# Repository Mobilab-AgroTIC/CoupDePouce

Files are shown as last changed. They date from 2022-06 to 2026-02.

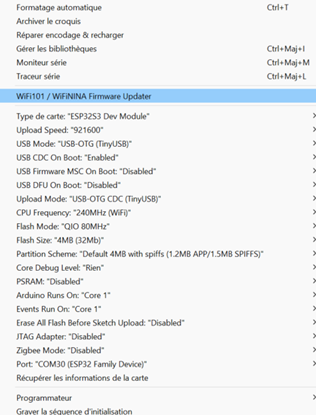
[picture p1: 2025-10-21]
firmware/CoupDePouce_ESP32S3_LTE/config.png

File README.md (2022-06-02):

# CoupDePouce

Le projet permet d'activer un mécansime à distance, via la construction d'un 'doigt connecté', par envoi de SMS. Le système total coûte environ 60€.
Dans ce tutoriel, nous allons d'abord cosntruire le module (1), puis le programmer (2) pour qu'il s'actionne à la récéption d'un SMS.

# 1. Construction du système CoupDePouce

## 1.1. Matériel nécessaire

CoupDePouce nécéssite : 
  - une carte Arduino [MKR GSM 1400](https://www.kubii.fr/26-arduino/2911-arduino-mkr-gsm-1400-3272496301078.html) ou [NB 1500](https://www.gotronic.fr/art-carte-arduino-mkr-nb-1500-abx00019-28733.htm) : 40€
  - Une antenne associée
  - Un forfait téléphonique le moins cher possible : le site [monpetitforfait](https://www.monpetitforfait.com/comparatif-forfaits-mobiles-2-euros) propose les bons plans du moment, il est assez facile de trouver un forfait à 2€/mois chez [Prixtel](https://www.prixtel.com/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) ou [Syma](https://www.symamobile.com/forfait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). Free propose un forfait à 0€/mois si vous êtes déja client chez eux.
  - un moteur "pas à pas" [28byj-48](https://fr.aliexpress.com/item/32906617266.html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) avec sa carte ULN2003 (inclue) : 2€
  - Un [cable micro USB data](https://fr.aliexpress.com/item/32958208619.html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) (Attention : si vous avez déja ce cable pour votre téléphone ou autre, il faut être bien sûr que l'on peut echanger de la donnée via ce câble (data sync), et pas uniquement recharger)
  - Un [adaptateur 220V/USB](https://fr.aliexpress.com/item/1005002021554317.html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) (vous en avez peut-être un qui traine chez vous...?)
  - des [cables Dupont Femelle-Femelle](https://fr.aliexpress.com/item/4000848184096.html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) Bien choisir le cable femelle-femelle de 40cm, comme le montre la photo 1 : 

  

## 1.2. Montage du système 

Le montage éléctronique est très simple. Il faut impérativement brancher l'antenne sur la carte, puis les câbles comme suit :

MOTEUR <-> ARDUINO

- **"-"** <-> **pin GND**
- **"5V"** <-> **pin VCC**
- **IN1** <-> **pin 6**
- **IN2** <-> **pin 7**
- **IN3** <-> **pin 8**
- **IN4** <-> **pin 9**

# 2. Installation et paramétrage du logiciel Arduino

## 2.1. Installation d'Arduino

Si ceci n'est pas encore fait, il faut au préalable installer le [logiciel Arduino](https://www.arduino.cc/en/software) sur son ordinateur. Choisissez l'installation pour votre ordinateur (Windows, linux, mac, etc) comme le montre la photo 2 :


L'installation vous posera quelques questions, dites "oui" à tout.

## 2.2. Paramétrage d'Arduino pour la carte MKR GSM 1400 ou NB 1500

Une fois installé, on lance le logiciel Arduino. Une fenêtre s'ouvre.



On ouvre Outils > Type de cartes > Gestionnaire de Cartes



On recherce depuis la barre de recherche MKR. Une librairie est trouvée : "Arduino SAMD Boards". On clique sur Installer. L'installation peut prendre 1min.



On selectionne finalement la carte utilisée dans outils > Type de Carte > Arduino SAMD > Arduino MKR GSM 1400 : 



Tout est configuré ! 

## 2.3. Flash du code sur l'Arduino
On va maintenant installer le code sur la carte qui permettra de contrôler le moteur et l'utilisation de SMS.

Sur cette page Github, vous pouvez télécharger le code de CoupDePouce en cliquant sur le bouton vert Code > Download ZIP.


Le fichier téléchargé est à dézipper : 


Ouvrez ensuite CoupDePouce-main > Scripts > Arduino > CoupDePouce_1moteur > CoupDePouce_1moteur.ino 
. Une fenêtre Arduino s'ouvre. Notez qu'il y a deux onglets : 
CoupDePouce_1moteur.ino et arduino_secrets.h. Dans arduino_secrets.h, vous pouvez renseigner votre code PIN ainsi que le numéro de téléphone de 2 personnes qui recevront le message d'initialisation.



Le code est maintenant prêt à être envoyé sur la carte. Branchez l'arduino à l'ordinateur via la câble USB, puis allez dans Outils > Ports > COMxx. Il faut séléctionner le bon port COM, si vous en avez plusieurs à sipsosition, débranchez la carte Arduino et retournez dans cet onglet pour voir lequel a disparu. C'est celui la qu'il faudra prendre une fois quand vous l'aurez rebranché ;)


Cliquez finalement sur le bouton "Téléverser" (en blanc sur l'image) : 



Vous pouvez maintenant tester le système en le branchant sur le secteur via l'adaptateur

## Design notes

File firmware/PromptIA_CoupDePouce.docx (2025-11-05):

## Cahier des Charges pour CoupDePouce

### Présentation

CoupDePouce est un projet d’auto construction destiné à des agriculteurs, pour simplifier leur quotidien en activant à distance des automatismes (en appuyant sur des boutons). En envoyant un SMS, un « doigt » s’active, ce qui permet d’effectuer une action à distance. Cela est notamment utile pour appuyer sur un bouton de pompe d’irrigation.

Le projet s’adapte à plusieurs types de bouton (rotation, push bouton, …). Il passe par la 4G pour envoyer le SMS

### Matériel

CoupDePouce est constitué de :

- Une carte ESP32-S3-4G de chez MakerFabs : https://www.gotronic.fr/art-carte-esp32-s3-4g-lte-a7670e-38784.htm
- Un Servo moteur avec rétrocontrôle : https://www.gotronic.fr/art-servomoteur-fb5118m-36026.htm
- Une carte SIM (en fonction de l’opérateur qui couvre le mieux la zone)
- Une alimentation 5V.

### Firmware

Le code doit fonctionner sur le logiciel ArduinoIDE.

Il doit pouvoir accepter plusieurs servo moteurs. Chaque servo est identifié par une lettre. Par défaut il y en a 2, mais si on copie colle la définition d’un servo, on peut en créer un C, un D, …

Voici un exemple :
Servo A :

- Sa broche SERVOA_PIN
- Son type ROTATE ou PUSH
- Son angle max (il va de 0° (en mode OFF) à n° (en mode ON). A noter que pour un bouton de type Rotate, le servo recevant un message d’activation ira de 0 à angleMax, alors que si c’est un type Push, il fera 0° -> AngleMax -> 0°. On pourra également envoyer off (uniquement pour le bouton Rotate), qui fera angle Max -> 0°
- Son sens : horaire ou antihoraire

D’autres définitions sont demandées : le code PIN, les numéros des destinataires. Ces numéros seront utilisés pour renvoyer des SMS à TOUS les numéros listés, + celui qui vient d’envoyer le message si jamais il n’est pas dans la liste. Par exemple, au démarrage de CoupDePouce, tout le monde recevra :

« CoupDePouce operationnel. Envoyez 'A1' pour activer le bouton A. Envoyez ‘Help’ pour recevoir toutes les commandes possibles »

Dans l’idée, les commandes par SMS sont :

A1 : Si c’est un ROTATE, tourne le servo du bouton A de 0° à AngleMax°. Si C’est PUSH, faire 0°->AngleMax°->0°

A0 : Si c’est un ROTATE, tourne le servo du bouton A de AngleMax° à 0°

B1 : Si c’est un ROTATE, tourne le servo du bouton B de 0° à AngleMax°. Si C’est PUSH, faire 0°->AngleMax°->0°

B0 : Si c’est un ROTATE, tourne le servo du bouton B de AngleMax° à 0°

Si d’autres servos sont définis, on peut envoyer C1, C0, D1, … En fonction du nombre de servos définis.

La code suivant inclue des fonctions de déclaration de code SIM, les AT pour bien vérifier que tout fonctionne, ...

Par contre il ne marche que pour 1 servo, eet que avec un bouton PUSH, qui reçoit uniquement la commande « 1 » .

Point important : Si un message n’est pas reçu par quelconque bug, il ne faut pas qu’il soit conservé ! Sinon, si il est reçu genre 1h après, il ne faut absolument pas effectuer d’action sur les boutons. Il faut donc flush tout ancien message avant que le coupdepouce soit en mode « paré à écouter les prochains messages ». C’est important car CoupDePouce doit etre opérationnel en temps réel !

#include <Arduino.h>

#include <ESP32Servo.h>

// === CODE PIN ET NUMEROS ===

// Mets ton code PIN entre les guillemets ci-dessous, ex: "1234". Laisse "" si pas de PIN.

#define SIM_PIN "0000"

// Remplace les numéros ci-dessous par les numéros de téléphone (Sans espace, et au format international (+33 pour la France))

// Chaque numéro est entre guillemets "" et séparés par une virgule "," (après le dernier numéro, pas de virgule).

static const char* DESTS[] = {

"+336xxxxxxxx",

"+336xxxxxxxx"

};

const size_t N_DESTS = sizeof(DESTS) / sizeof(DESTS[0]);

// === Servo ===

Servo myservo;

#define SERVO_PIN 40

// === UART modem (A7670E) ===

HardwareSerial SerialAT(2);

#define IO_RXD2 47

#define IO_TXD2 48

#define IO_GSM_PWRKEY 4

// --------- Utils AT ----------

static void purgeInput(uint32_t ms=50) {

uint32_t t0 = millis();

while (millis() - t0 < ms) {

while (SerialAT.available()) (void)SerialAT.read();

delay(1);

}

}

static void sendAT(const char* cmd) {

Serial.print(">> "); Serial.println(cmd);

SerialAT.print(cmd); SerialAT.print("\r\n");

}

bool waitFor(const char* token, uint32_t timeout_ms = 3000) {

uint32_t t0 = millis();

String buf;

while (millis() - t0 < timeout_ms) {

while (SerialAT.available()) {

char c = (char)SerialAT.read();

buf += c;

if (buf.indexOf(token) >= 0) return true;

}

delay(1);

}

return false;

}

// --------- Power modem ----------

static void modem_power_on() {

pinMode(IO_GSM_PWRKEY, OUTPUT);

digitalWrite(IO_GSM_PWRKEY, HIGH);

delay(100);

digitalWrite(IO_GSM_PWRKEY, LOW); // A76xx: impulsion basse ~1.2s

delay(1200);

digitalWrite(IO_GSM_PWRKEY, HIGH);

delay(3000);

}

// --------- Réseau ----------

static bool waitNetwork(uint32_t max_ms = 60000) {

uint32_t t0 = millis();

while (millis() - t0 < max_ms) {

sendAT("AT+CEREG?");

String buf; uint32_t t1 = millis();

while (millis() - t1 < 1000) {

while (SerialAT.available()) buf += (char)SerialAT.read();

}

Serial.print(buf);

if (buf.indexOf(",1") >= 0 || buf.indexOf(",5") >= 0) return true; // registered / roaming

delay(800);

}

return false;

}

// --------- Envoi SMS ----------

static bool sendSMS(const String& text, const char* number) {

purgeInput();

Serial.printf("Envoi SMS à %s : \"%s\"\n", number, text.c_str());

SerialAT.print("AT+CMGS=\"");

SerialAT.print(number);

SerialAT.print("\"\r\n");

if (!waitFor(">", 5000)) {

Serial.println("! Prompt '>' non reçu");

return false;

}

SerialAT.print(text);

SerialAT.write(0x1A); // Ctrl-Z

if (!waitFor("OK", 15000)) {

Serial.println("! OK final non reçu");

return false;

}

return true;

}

static void sendSMSAll(const String& text) {

for (size_t i=0;i<N_DESTS;i++) {

bool ok = sendSMS(text, DESTS[i]);

Serial.printf("[SMS -> %s] %s\n", DESTS[i], ok ? "OK" : "ECHEC");

delay(400);

}

}

// --------- Servo ----------

static void moveServo(int minAngle, int maxAngle) {

if (minAngle < 0) minAngle = 0;

if (maxAngle > 180) maxAngle = 180;

myservo.attach(SERVO_PIN, 500, 2500);

for (int p = minAngle; p <= maxAngle; p++) { myservo.write(p); delay(15); }

delay(1000);

for (int p = maxAngle; p >= minAngle; p--) { myservo.write(p); delay(15); }

delay(300);

myservo.detach();

pinMode(SERVO_PIN, INPUT_PULLDOWN); // évite que le fil signal flotte

}

// --------- SETUP ----------

void setup() {

Serial.begin(115200);

delay(1200);

Serial.println("\n[CoupDePouce - ESP32-S3 + A7670E | Fire&Forget SMS]");

SerialAT.begin(115200, SERIAL_8N1, IO_RXD2, IO_TXD2);

SerialAT.setRxBufferSize(4096);

modem_power_on();

// Sync modem

for (int i = 0; i < 5; i++) {

sendAT("AT");

if (waitFor("OK")) break;

delay(100);

}

// Echo off, erreurs verbeuses (facultatif)

sendAT("ATE0");

sendAT("AT+CMEE=2");

// PIN ?

sendAT("AT+CPIN?");

String r;

uint32_t t=millis();

while (millis()-t < 1200) {

while (SerialAT.available()) r += (char)SerialAT.read(); }

if (r.indexOf("READY") >= 0) {

Serial.println("SIM OK");

} else if (r.indexOf("SIM PIN") >= 0) {

if (SIM_PIN && *SIM_PIN) {

SerialAT.printf("AT+CPIN=\"%s\"\r\n", SIM_PIN);

waitFor("READY", 8000);

} else {

Serial.println("PIN requis (SIM_PIN vide)");

}

} else if (r.indexOf("SIM PUK") >= 0) {

Serial.println("SIM bloquée (PUK)");

} else if (r.indexOf("NOT INSERTED") >= 0) {

Serial.println("Pas de SIM");

}

Serial.println("Attente réseau...");

if (!waitNetwork(60000)) Serial.println("Réseau KO (timeout)");

else Serial.println("Réseau OK");

// Mode SMS texte, alphabet GSM

sendAT("AT+CMGF=1");

sendAT("AT+CSCS=\"GSM\"");

// CNMI=2,2 : pas de stockage, le modem “push” le SMS sur l’UART immédiatement.

sendAT("AT+CNMI=2,2,0,0,0");

// Vider d’éventuels anciens SMS stockés (pour éviter toute lecture différée)

sendAT("AT+CPMS=\"SM\",\"SM\",\"SM\"");

sendAT("AT+CMGD=1,4");

sendAT("AT+CPMS=\"ME\",\"ME\",\"ME\"");

sendAT("AT+CMGD=1,4");

// Message de démarrage

sendSMSAll("CoupDePouce operationnel. Envoyez '1' pour activer.");

// Petit mouvement de test

moveServo(0,20);

}

// --------- LOOP (URC only) ----------

void loop() {

// On lit ligne par ligne. Si on voit '+CMT:' -> la prochaine ligne est le corps du SMS.

static String line;

static bool waitBody = false;

static String lastHeader;

while (SerialAT.available()) {

char c = (char)SerialAT.read();

if (c == '\r') continue;

if (c != '\n') {

line += c;

continue;

}

// Fin de ligne

String cur = line;

line = "";

if (cur.length() == 0) continue; // ignore lignes vides

Serial.print("[URC] "); Serial.println(cur);

if (waitBody) {

// 'cur' = corps du SMS en mode texte

String body = cur;

body.replace("\"", "");

body.trim();

Serial.print("SMS reçu (body): "); Serial.println(body);

// Seuil d'action : "1", " 1", "1 "

if (body == "1" || body == "1 " || body == " 1") {

Serial.println(">> ALLUMAGE");

sendSMSAll("allumage...");

moveServo(0, 90);

} else {

Serial.println("Commande non reconnue (ignorée).");

}

waitBody = false; // traiter une seule ligne de corps

lastHeader = "";

continue;

}

if (cur.startsWith("+CMT:")) {

// Exemple header : +CMT: "+33699....",,"25/10/21,15:10:00+08"

lastHeader = cur;

waitBody = true; // la prochaine ligne sera le corps

continue;

}

}

}

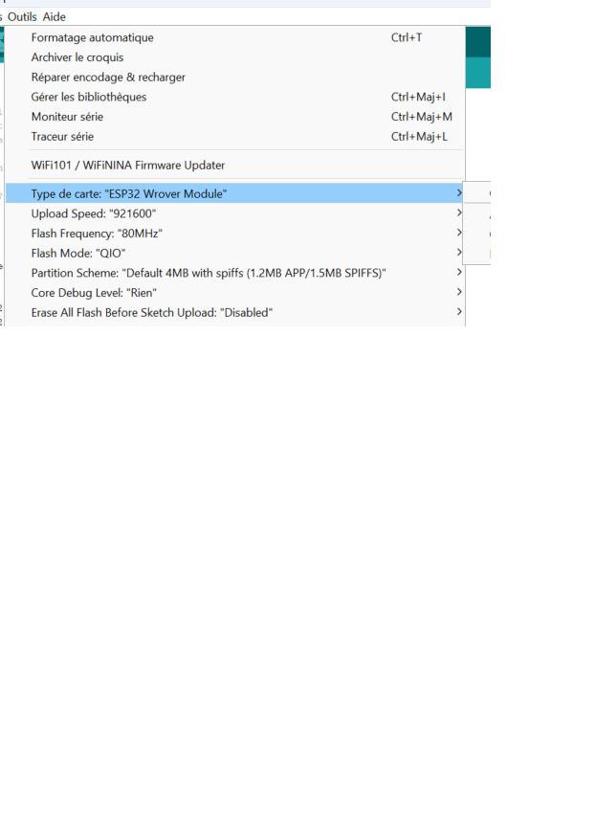
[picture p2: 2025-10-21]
Scripts/LilyGo/Sans titre.png

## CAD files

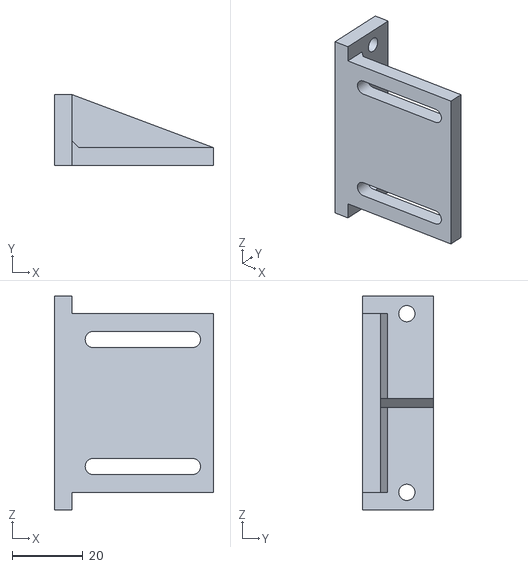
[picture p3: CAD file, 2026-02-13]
hardware/servo/exports/Patte_fixation.stl
45.0 x 20.0 x 60.5

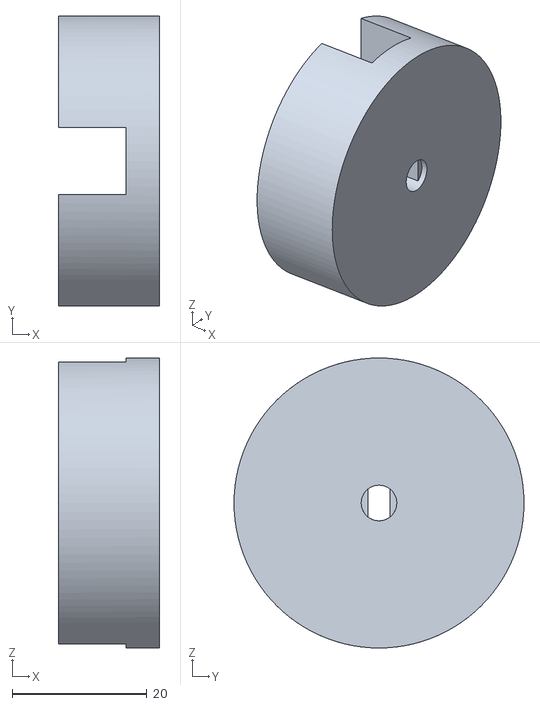
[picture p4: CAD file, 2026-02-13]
hardware/step/exports/Bouton_rotatif_BYJ48.stl
15.0 x 43.1 x 43.1

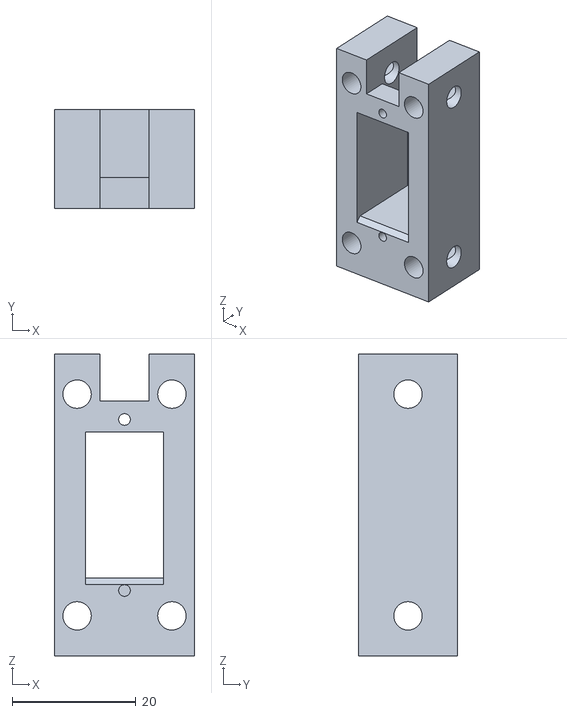
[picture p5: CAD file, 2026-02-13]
hardware/servo/exports/Support_FT90B.stl
22.7 x 16.0 x 48.9

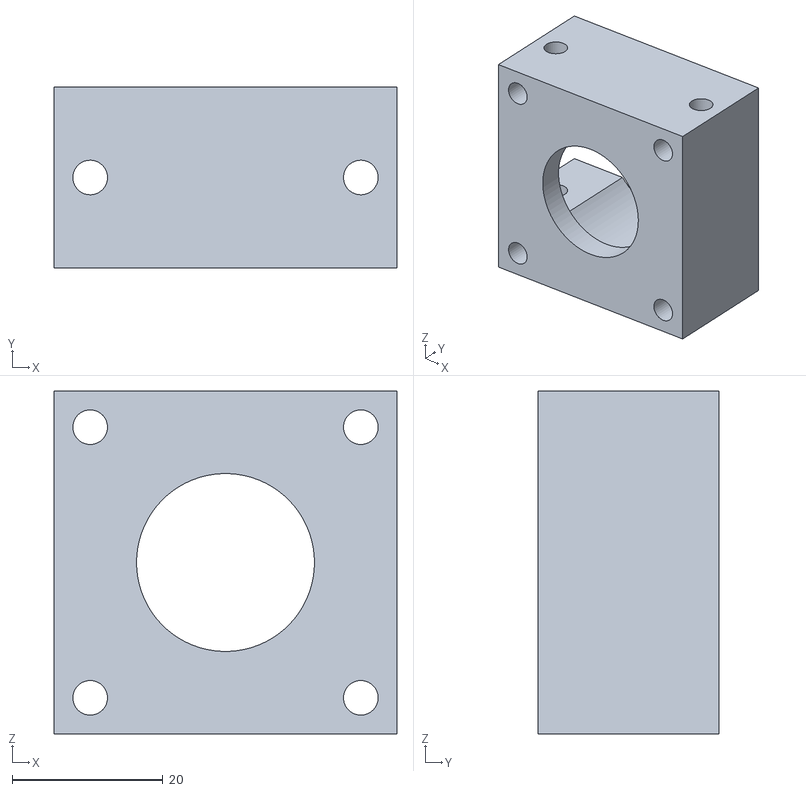
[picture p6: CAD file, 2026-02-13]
hardware/step/exports/Support_BYJ48.stl
45.5 x 24.0 x 45.5

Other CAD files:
hardware/CoupDePouce.f3d

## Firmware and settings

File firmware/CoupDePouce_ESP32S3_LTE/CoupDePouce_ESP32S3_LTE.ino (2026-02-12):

#include <Arduino.h>
#include <ESP32Servo.h>

// ================== CONFIG LIGNE / SIM ==================
// Mets ton code PIN entre guillemets (laisser "" si pas de PIN)
#define SIM_PIN "0000"

// Numéros destinataires en format international
static const char* DESTS[] = {
  "+336xxxxxxxx",
};

const size_t N_DESTS = sizeof(DESTS) / sizeof(DESTS[0]);

// ================== SERVOS ==================
enum ServoType { ROTATE = 0, PUSH = 1 };
enum clockWise { ANTIHORAIRE = 0, HORAIRE = 1 };

struct ServoConf {
  char      id;          // 'A', 'B', ...
  int       pin;         // broche ESP32-S3
  ServoType type;        // ROTATE ou PUSH
  int       angleMax;    // 0..180
  clockWise clockwise;   // true: sens horaire, false: anti-horaire
};

// --- AJUSTE ICI TES SERVOS (ex: A/B par défaut) ---
static ServoConf SERVOS[] = {
  //  id  , Broche,  type , angleMax, Sens
  {   'A' , 40 , PUSH , 90 , HORAIRE     },
  // {   'B' , 41 , ROTATE   , 60 , ANTIHORAIRE }, 
};

const size_t N_SERVOS = sizeof(SERVOS) / sizeof(SERVOS[0]);

// Moteur servo unique réutilisé (un à la fois)
Servo g_servo;

// ================== MODEM A7670E (UART2) ==================
HardwareSerial SerialAT(2);

#define IO_RXD2         47
#define IO_TXD2         48
#define IO_GSM_PWRKEY    4

// ================== OUTILS AT ==================
static void purgeInput(uint32_t ms=50) {
  uint32_t t0 = millis();
  while (millis() - t0 < ms) {
    while (SerialAT.available()) (void)SerialAT.read();
    delay(1);
  }
}

static void sendAT(const char* cmd) {
  Serial.print(">> "); Serial.println(cmd);
  SerialAT.print(cmd); SerialAT.print("\r\n");
}

static bool waitFor(const char* token, uint32_t timeout_ms = 3000) {
  uint32_t t0 = millis();
  String buf;
  while (millis() - t0 < timeout_ms) {
    while (SerialAT.available()) {
      char c = (char)SerialAT.read();
      buf += c;
      if (buf.indexOf(token) >= 0) return true;
    }
    delay(1);
  }
  return false;
}

static void modem_power_on() {
  pinMode(IO_GSM_PWRKEY, OUTPUT);
  digitalWrite(IO_GSM_PWRKEY, HIGH);
  delay(100);
  digitalWrite(IO_GSM_PWRKEY, LOW);   // impulsion ~1.2s
  delay(1200);
  digitalWrite(IO_GSM_PWRKEY, HIGH);
  delay(3000);
}

static bool waitNetwork(uint32_t max_ms = 60000) {
  uint32_t t0 = millis();
  while (millis() - t0 < max_ms) {
    sendAT("AT+CEREG?");
    String buf; uint32_t t1 = millis();
    while (millis() - t1 < 1000) { while (SerialAT.available()) buf += (char)SerialAT.read(); }
    Serial.print(buf);
    if (buf.indexOf(",1") >= 0 || buf.indexOf(",5") >= 0) return true; // registered / roaming
    delay(800);
  }
  return false;
}

// ================== SMS ==================
static bool sendSMS(const String& text, const char* number) {
  purgeInput();
  Serial.printf("Envoi SMS à %s : \"%s\"\n", number, text.c_str());

  SerialAT.print("AT+CMGS=\"");
  SerialAT.print(number);
  SerialAT.print("\"\r\n");

  if (!waitFor(">", 5000)) { Serial.println("! Prompt '>' non reçu"); return false; }

  SerialAT.print(text);
  SerialAT.write(0x1A); // Ctrl-Z

  if (!waitFor("OK", 15000)) { Serial.println("! OK final non reçu"); return false; }
  return true;
}

static void sendSMSAll(const String& text) {
  for (size_t i=0; i<N_DESTS; i++) {
    bool ok = sendSMS(text, DESTS[i]);
    Serial.printf("[SMS -> %s] %s\n", DESTS[i], ok ? "OK" : "ECHEC");
    delay(400);
  }
}

static bool isKnownDest(const String& number) {
  for (size_t i=0; i<N_DESTS; i++) {
    if (number == DESTS[i]) return true;
  }
  return false;
}

static void sendSMSAllPlusSender(const String& text, const String& sender) {
  sendSMSAll(text);
  if (sender.length() && !isKnownDest(sender)) {
    (void)sendSMS(text, sender.c_str());
  }
}

// ================== UTILS PARSING ==================
static int findServoIndexById(char id) {
  char up = toupper((unsigned char)id);
  for (size_t i=0; i<N_SERVOS; i++) if (toupper(SERVOS[i].id) == up) return (int)i;
  return -1;
}

static String extractNumberFromCMT(const String& header) {
  // Exemple header: +CMT: "+33699....",,"25/10/21,15:10:00+08"
  int p1 = header.indexOf('\"');
  if (p1 < 0) return "";
  int p2 = header.indexOf('\"', p1+1);
  if (p2 < 0) return "";
  return header.substring(p1+1, p2);
}

static String buildHelpText() {
  String s = "CoupDePouce operationnel.\n";
  s += "Commandes:\n";
  for (size_t i=0; i<N_SERVOS; i++) {
    const ServoConf& c = SERVOS[i];
    s += String(c.id) + "1: ";
    s += (c.type==ROTATE) ? "ON (0->" : "PUSH (0->";
    s += String(c.angleMax) + (c.type==PUSH? "->0)\n" : ")\n");
    if (c.type==ROTATE) s += String(c.id) + "0: OFF (" + String(c.angleMax) + "->0)\n";
  }
  s += "HELP: ce message.";
  return s;
}

// ================== SERVO MOUVEMENT ==================
static void attachForPin(int pin) {
  g_servo.attach(pin, 500, 2500); // PWM 50 Hz (~500-2500µs)
}

static void detachAndFloat(int pin) {
  g_servo.detach();
  pinMode(pin, INPUT_PULLDOWN);
}

static void sweep(int from, int to, int stepDelayMs=12) {
  if (from <= to) {
    for (int a=from; a<=to; a++) { g_servo.write(a); delay(stepDelayMs); }
  } else {
    for (int a=from; a>=to; a--) { g_servo.write(a); delay(stepDelayMs); }
  }
}

// Convertit 0/AngleMax logiques vers angles physiques selon sens
static int physAngle(int logicalAngle, const ServoConf& c) {
  // logique: 0 = OFF, angleMax = ON
  if (c.clockwise) return logicalAngle;
  // anti-horaire: on inverse autour de 90? Non: on suppose map simple 0..180 -> 180..0
  return 180 - logicalAngle;
}

static void action_ON(const ServoConf& c) {
  attachForPin(c.pin);
  int offA = physAngle(0, c);
  int onA  = physAngle(c.angleMax, c);
  sweep(offA, onA);
  if (c.type == PUSH) {
    delay(250);
    sweep(onA, offA);
  }
  delay(200);
  detachAndFloat(c.pin);
}

static void action_OFF(const ServoConf& c) {
  if (c.type == PUSH) return; // non applicable
  attachForPin(c.pin);
  int offA = physAngle(0, c);
  int onA  = physAngle(c.angleMax, c);
  sweep(onA, offA);
  delay(200);
  detachAndFloat(c.pin);
}

// ================== SETUP ==================
void setup() {
  Serial.begin(115200);
  delay(1200);
  Serial.println("\n[CoupDePouce - ESP32-S3 + A7670E | Multi-servos SMS]");

  SerialAT.begin(115200, SERIAL_8N1, IO_RXD2, IO_TXD2);
  SerialAT.setRxBufferSize(4096);

  // Petit clignotement de vie via log
  modem_power_on();

  // Sync modem
  for (int i=0; i<5; i++) { sendAT("AT"); if (waitFor("OK", 800)) break; delay(150); }

  sendAT("ATE0");       // echo off
  sendAT("AT+CMEE=2");  // erreurs verbeuses

  // PIN SIM ?
  sendAT("AT+CPIN?");
  {
    String r; uint32_t t=millis();
    while (millis()-t < 1500) { while (SerialAT.available()) r += (char)SerialAT.read(); }
    if (r.indexOf("READY") >= 0) {
      Serial.println("SIM OK");
    } else if (r.indexOf("SIM PIN") >= 0) {
      if (SIM_PIN && *SIM_PIN) {
        SerialAT.printf("AT+CPIN=\"%s\"\r\n", SIM_PIN);
        waitFor("READY", 8000);
      } else {
        Serial.println("PIN requis (SIM_PIN vide)");
      }
    } else if (r.indexOf("SIM PUK") >= 0) {
      Serial.println("SIM bloquee (PUK)");
    } else if (r.indexOf("NOT INSERTED") >= 0) {
      Serial.println("Pas de SIM");
    }
  }

  Serial.println("Attente reseau...");
  if (!waitNetwork(60000)) Serial.println("Reseau KO (timeout)");
  else Serial.println("Reseau OK");

  // Mode SMS texte, alphabet GSM
  sendAT("AT+CMGF=1");
  sendAT("AT+CSCS=\"GSM\"");

  // *** IMPORTANT : URC direct, pas de stockage des nouveaux SMS
  sendAT("AT+CNMI=2,2,0,0,0");

  // *** Purge des anciens SMS stockés (SM & ME) avant d'écouter
  sendAT("AT+CPMS=\"SM\",\"SM\",\"SM\"");
  sendAT("AT+CMGD=1,4");
  sendAT("AT+CPMS=\"ME\",\"ME\",\"ME\"");
  sendAT("AT+CMGD=1,4");

  // Message d'accueil + petit mouvement de test pour chaque servo
  String help = buildHelpText();
  sendSMSAll(help);

  for (size_t i=0; i<N_SERVOS; i++) {
    const ServoConf& c = SERVOS[i];
    attachForPin(c.pin);
    int offA = physAngle(0, c);
    int onA  = physAngle(min(c.angleMax, 20), c);
    sweep(offA, onA, 8);
    sweep(onA, offA, 8);
    detachAndFloat(c.pin);
    delay(120);
  }
}

// ================== LOOP (URC only) ==================
void loop() {
  static String line;
  static bool   waitBody   = false;
  static String lastHeader;

  while (SerialAT.available()) {
    char c = (char)SerialAT.read();
    if (c == '\r') continue;
    if (c != '\n') { line += c; continue; }

    // Fin de ligne
    String cur = line; line = "";
    if (cur.length() == 0) continue;

    Serial.print("[URC] "); Serial.println(cur);

    if (waitBody) {
      String body = cur;
      body.replace("\"", "");
      body.trim();
      String sender = extractNumberFromCMT(lastHeader);

      Serial.print("SMS recu de "); Serial.print(sender); Serial.print(" : "); Serial.println(body);

      // Normalisation
      body.toUpperCase();

      // HELP ?
      if (body == "HELP" || body == "H") {
        sendSMSAllPlusSender(buildHelpText(), sender);
        waitBody=false; lastHeader=""; continue;
      }

      // Forme X0 / X1 attendue
      bool valid = false;
      if (body.length() == 2) {
        char sid = body.charAt(0);
        char cmd = body.charAt(1);
        int idx = findServoIndexById(sid);
        if (idx >= 0 && (cmd=='0' || cmd=='1')) {
          const ServoConf& conf = SERVOS[idx];
          if (cmd == '1') {
            valid = true;
            sendSMSAllPlusSender(String("OK ")+conf.id+"1", sender);
            action_ON(conf);
          } else { // '0'
            if (conf.type == ROTATE) {
              valid = true;
              sendSMSAllPlusSender(String("OK ")+conf.id+"0", sender);
              action_OFF(conf);
            } else {
              // PUSH n'a pas de OFF
              sendSMSAllPlusSender(String("Commande ")+conf.id+"0 non applicable (PUSH).", sender);
            }
          }
        }
      }

      if (!valid && body.length() == 1 && (body[0] >= 'A' && body[0] <= 'Z')) {
        // Permettre 'A' seul => ON (alias pratique)
        int idx = findServoIndexById(body[0]);
        if (idx >= 0) {
          const ServoConf& conf = SERVOS[idx];
          sendSMSAllPlusSender(String("OK ")+conf.id+"1", sender);
          action_ON(conf);
          valid = true;
        }
      }

      if (!valid) {
        sendSMSAllPlusSender("Commande non reconnue. Envoie 'HELP'.", sender);
      }

      waitBody = false;
      lastHeader = "";
      continue;
    }

    if (cur.startsWith("+CMT:")) {
      lastHeader = cur;
      waitBody   = true;   // prochaine ligne = corps
      continue;
    }
  }
}

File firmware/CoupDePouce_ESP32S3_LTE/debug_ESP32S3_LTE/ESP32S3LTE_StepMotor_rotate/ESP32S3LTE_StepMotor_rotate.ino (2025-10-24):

#include <Arduino.h>

// === Broches (modifie l'ordre si ton IN1..IN4 n'est pas 39,40,41,42) ===
const int PIN_IN1 = 39;
const int PIN_IN2 = 40;
const int PIN_IN3 = 41;
const int PIN_IN4 = 42;

// === Séquence demi-pas (8 états) : 4096 pas / tour sur 28BYJ-48 ===
const uint8_t HALFSTEP_SEQ[8][4] = {
  {1,0,0,0},
  {1,1,0,0},
  {0,1,0,0},
  {0,1,1,0},
  {0,0,1,0},
  {0,0,1,1},
  {0,0,0,1},
  {1,0,0,1}
};

const int STEPS_PER_REV = 4096;   // demi-pas
float rpm = 10.0;                 // vitesse cible
unsigned long stepDelayUs = 0;    // µs entre demi-pas (calculé)

int seqIndex = 0;                 // index 0..7

void outPhase(const uint8_t p[4]) {
  digitalWrite(PIN_IN1, p[0]);
  digitalWrite(PIN_IN2, p[1]);
  digitalWrite(PIN_IN3, p[2]);
  digitalWrite(PIN_IN4, p[3]);
}

void stepCW() {                   // sens horaire
  seqIndex = (seqIndex + 1) & 7;
  outPhase(HALFSTEP_SEQ[seqIndex]);
  delayMicroseconds(stepDelayUs);
}
void stepCCW() {                  // sens anti-horaire
  seqIndex = (seqIndex + 7) & 7;
  outPhase(HALFSTEP_SEQ[seqIndex]);
  delayMicroseconds(stepDelayUs);
}

void setRPM(float newRPM) {
  rpm = newRPM;
  // 1 tour = STEPS_PER_REV demi-pas, donc pas/s = rpm * steps/60
  float stepsPerSec = (rpm * STEPS_PER_REV) / 60.0f;
  if (stepsPerSec < 1.0f) stepsPerSec = 1.0f; // garde-fou
  stepDelayUs = (unsigned long)(1e6 / stepsPerSec);
}

void releaseCoils() { // optionnel : coupe le courant (évite de chauffer, moins de couple)
  digitalWrite(PIN_IN1, LOW);
  digitalWrite(PIN_IN2, LOW);
  digitalWrite(PIN_IN3, LOW);
  digitalWrite(PIN_IN4, LOW);
}

void setup() {
  pinMode(PIN_IN1, OUTPUT);
  pinMode(PIN_IN2, OUTPUT);
  pinMode(PIN_IN3, OUTPUT);
  pinMode(PIN_IN4, OUTPUT);
  setRPM(10.0);                   // 10 RPM par défaut
  outPhase(HALFSTEP_SEQ[seqIndex]); // position initiale
}

void loop() {
  // Exemple : 1 tour CW, pause, 1 tour CCW, pause
  for (int i = 0; i < STEPS_PER_REV; ++i) stepCW();
  releaseCoils(); delay(300);

  for (int i = 0; i < STEPS_PER_REV; ++i) stepCCW();
  releaseCoils(); delay(500);
}

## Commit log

2025-09-30 add 3D print folder and files for servomotor
    [Patte_fixation.stl, Support_FT90B.stl]
2025-09-30 FT90B support ok, BYJ48 ok, need to be printed
    [Patte_fixation.stl, Support_BYJ48.stl, Support_FT90B.stl]
2025-09-30 ajout contrefort patte fixation
    [Patte_fixation.stl]
2025-10-21 Ajout des codes pour carte MakerFabs
2025-10-21 arborescence 3D
    [Patte_fixation.stl, Support_BYJ48.stl, Support_FT90B.stl]
2026-02-13 Impression3D finalisee
    [Bouton_rotatif_BYJ48.stl, CoupDePouce.f3d, Patte_fixation.stl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]
